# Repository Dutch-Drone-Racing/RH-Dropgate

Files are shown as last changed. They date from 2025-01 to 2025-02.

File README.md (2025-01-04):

# RH-Plugin-Dropgate

A RotorHazard plugin that adds functionality for an automatic dropgate.

## Features

- Control a dropgate using a Raspberry Pi GPIO pin.
- Configure the GPIO pin directly from the RotorHazard settings menu.
- Optionally set up a mirrored timer for advanced synchronization.

---

## Installation

1. **Set up RotorHazard**  
   Install RotorHazard on your Raspberry Pi (Zero or compatible).

2. **Add the Plugin**  
   Copy the entire contents of the `RH-Dropgate-Plugin` directory into the RotorHazard plugin directory on your Raspberry Pi.

3. **Configure GPIO**  
   If you're not using the default GPIO pin (12), specify a different GPIO pin in the RotorHazard settings menu.

4. **Optional: Use a Mirror Timer**  
   For advanced setups, configure a mirror timer as described in the [RotorHazard mirror documentation](https://github.com/RotorHazard/RotorHazard/blob/main/doc/Cluster.md).

---

## Required Hardware

### **Recommended Raspberry Pi**

- **Raspberry Pi Zero W / Zero 2 W**  
   Affordable and compact, ideal for this project.  
- **Other Options (RPI3/4/5)**  
   These are compatible but may require a different case and are more expensive.

---

### **Power Supplies**

- **12V BEC**  
   Ensure at least 5A capacity for the electromagnets.  
   - Recommended: XL4015 or XL4005.

- **5V BEC**  
   Powers the Raspberry Pi.  
   - Example: Mateksys 30 to 5V BEC.

---

### **Relay**

- **12V Relay**  
   Requires a minimum of 5A capacity (higher is better).  
   - Example: [TinyTronics 12V Relay](https://www.tinytronics.nl/nl/schakelaars/relais/12v-relais-1-channel-hoog-actief-of-laag-actief-30a).

---

### **Electromagnets**

- **12V 40mm Electromagnets**  
   Requires 2 magnets. Designed for 40mm versions, such as the 25KG JF-XP4020 model.  
   The dropgate's round bar may reduce the magnet's efficiency, so choose stronger magnets when possible.  
   - Example: [JF-XP4020](https://www.tinytronics.nl/nl/mechanica-en-actuatoren/elektromagneten/elektromagneet-25kg-12v-dc-jf-xp4020).

---

### **Connectors**

- **XT60E Connectors**  
   - 2x XT60EF (Female).  
   - 3x XT60E (Male).

---

### **Optional: Micro USB (OTG) Ethernet Adapter**

While the Raspberry Pi Zero W has WiFi, a wired connection is more stable.

---

### **Double-Sided Tape**

Use tape to secure the relay, 5V BEC, and 12V BEC to the case.  
Recommended: Thick, heat-resistant tape (e.g., "gecko tape").

---

### **M3 Screws**

- **4x M3x6mm**: For the lid.  
- **4x M3x16mm**: For the Raspberry Pi Zero W bracket.  
- **6x M3x12mm**: For the XT60 connectors.

---

### **3D Prints**

- **1x Case**  
- **2x Magnet/Pole Holders**

3D print files are located in the `/prints` folder.

---

### **Other Hardware**

- **32mm Tubes**: Cut to desired lengths/heights.  
- **Aluminum Rod**: Matches the length of your dropgate banner.  
- **Metal Rod Ends**: Attach to the aluminum rod to stick to the magnets.

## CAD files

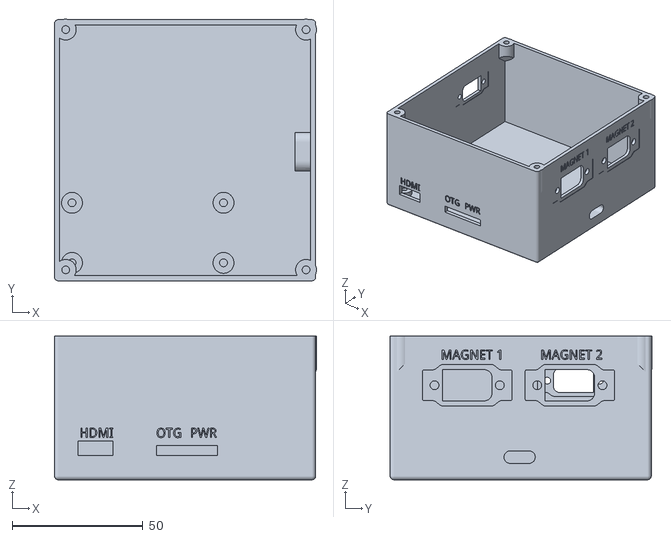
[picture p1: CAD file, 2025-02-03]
prints/Case/dropgate_case_v1_mr30.stl
100.3 x 100.2 x 55.0

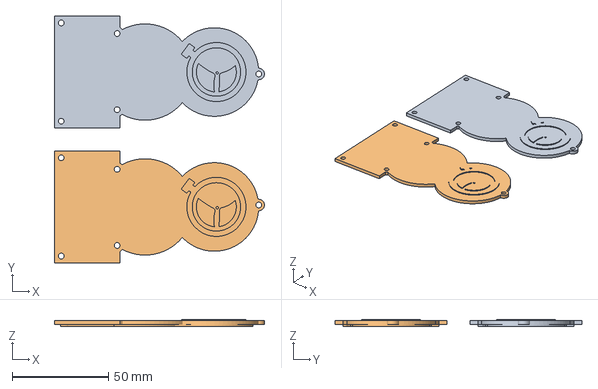
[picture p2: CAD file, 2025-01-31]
prints/Pole/dropgate_polemount_lid_right_logo.3mf
109.0 x 128.0 x 3.50 mm
dropgate_polemount_lid_right_logo.stl
dropgate_polemount_lid_left_logo.stl

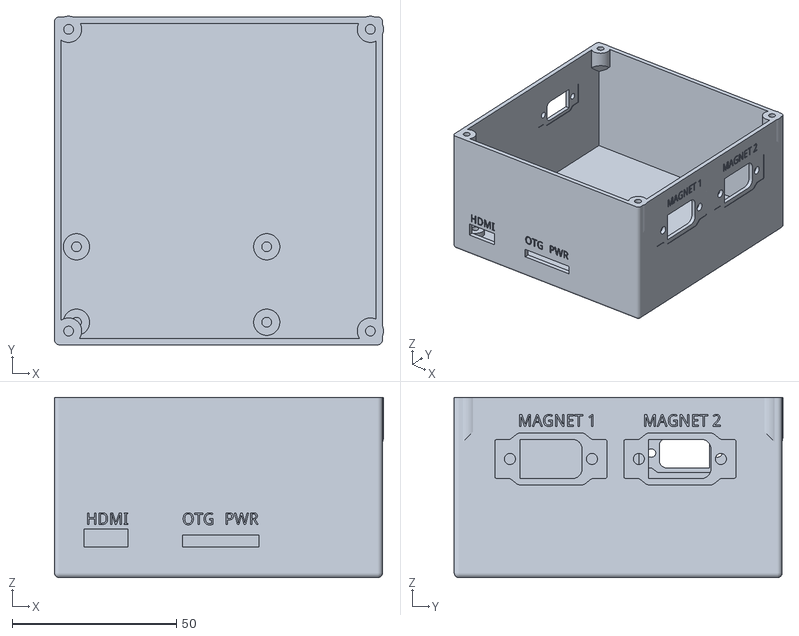
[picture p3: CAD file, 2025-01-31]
prints/Case/dropgate_case_v1.stl
100.3 x 100.2 x 55.0

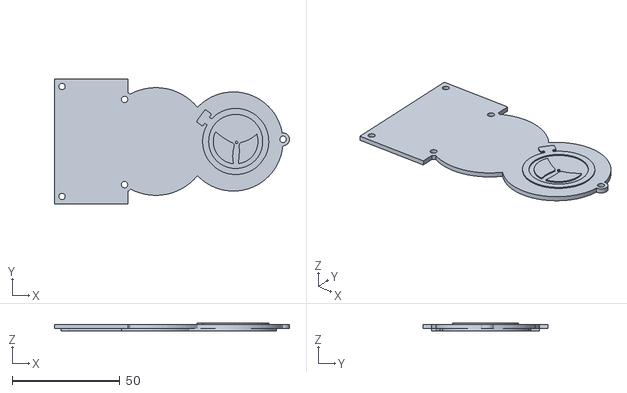
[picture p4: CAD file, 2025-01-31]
prints/Pole/dropgate_polemount_lid_left_logo.stl
109.0 x 58.0 x 3.50

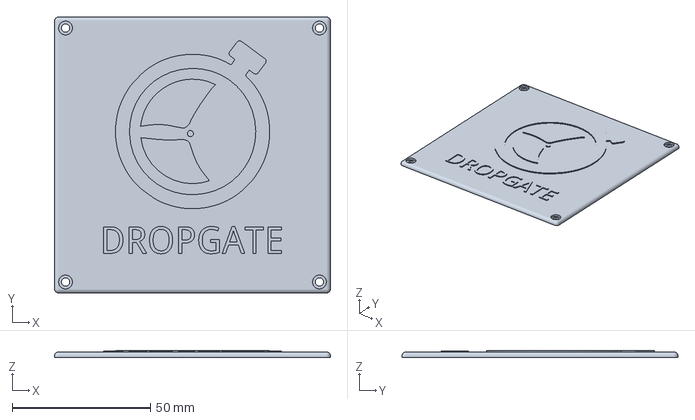
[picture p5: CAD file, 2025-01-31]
prints/Case/dropgate_lid_v1.3mf
100.0 x 100.0 x 2.50 mm

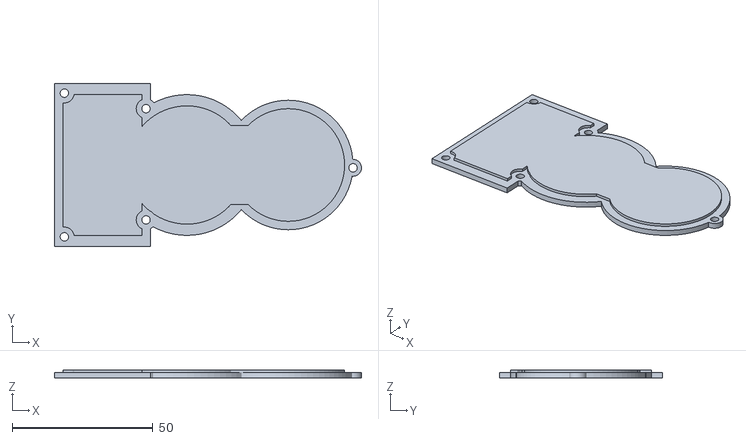
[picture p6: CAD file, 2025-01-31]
prints/Pole/dropgate_polemount_lid_left_nologo.stl
109.0 x 58.0 x 3.00

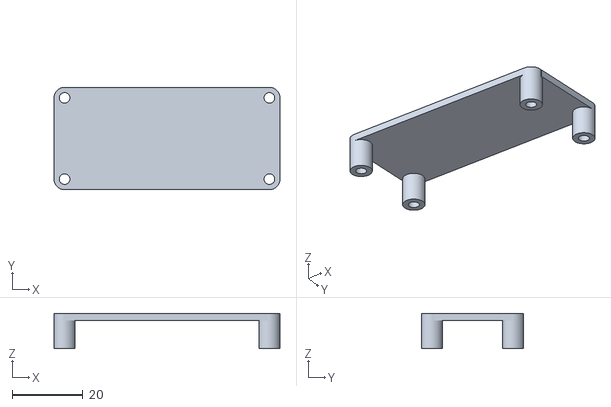
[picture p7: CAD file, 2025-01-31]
prints/Case/dropgate_regulator_bracket_v1.stl
64.0 x 29.0 x 10.0

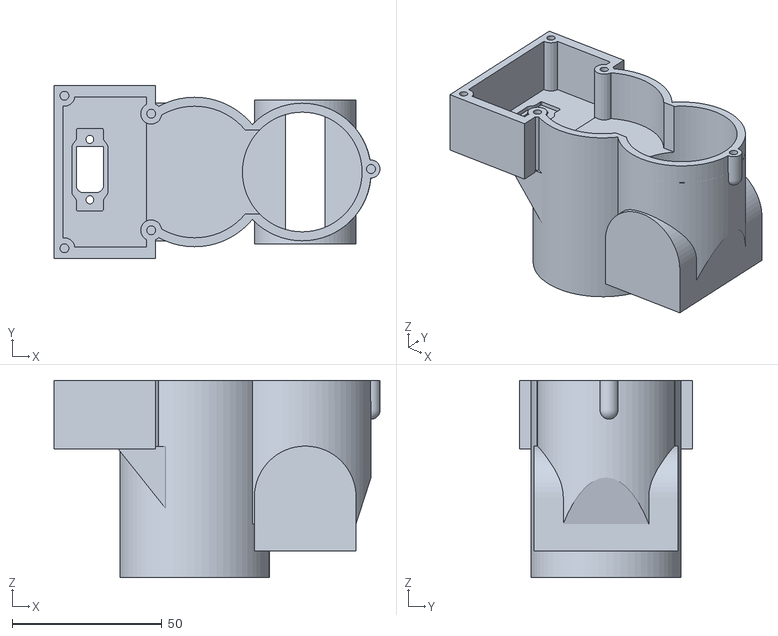
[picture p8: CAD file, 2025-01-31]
prints/Pole/dropgate_polemount_left.stl
109.0 x 58.0 x 66.0

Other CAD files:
prints/Pole/dropgate_polemount_lid_right_nologo.stl
prints/Pole/dropgate_polemount_right.stl
prints/Case/dropgate_lid_v1.stl
prints/Pole/dropgate_polemount_lid_right_logo.stl

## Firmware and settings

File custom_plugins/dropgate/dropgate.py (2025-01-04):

import logging
import RPi.GPIO as GPIO
from RHUI import UIField, UIFieldType, UIFieldSelectOption

class Dropgate():

    def __init__(self,rhapi):
        self.logger = logging.getLogger(__name__)
        self._rhapi = rhapi
        GPIO.setmode(GPIO.BCM)
        GPIO.setwarnings(False)

    def init_plugin(self,args):
        ui = self._rhapi.ui
        ui.register_panel("fpvscores_dropgate", "FPVScores Dropgate", "settings")
        ui_dropgate_gpio = UIField(name = 'fpvscores_dropgate_gpio', label = 'Dropgate GPIO', field_type = UIFieldType.BASIC_INT, desc = "Set the GPIO pin number for the dropgate", value = "12")
        fields = self._rhapi.fields
        fields.register_option(ui_dropgate_gpio, "fpvscores_dropgate")
        self.logger.info("Dropgate is ready")

    def setup_gpio(self, gpio_pin):
        GPIO.setup(gpio_pin, GPIO.OUT)
        GPIO.output(gpio_pin, GPIO.HIGH)

    def trigger_drop(self,args):
        fpvscores_dropgate_gpio = self._rhapi.db.option("fpvscores_dropgate_gpio")
        self.logger.info("Dropping gate on GPIO: %s" % fpvscores_dropgate_gpio)
        self.setup_gpio(fpvscores_dropgate_gpio)
        GPIO.output(fpvscores_dropgate_gpio, GPIO.LOW)

    def reactivate_drop(self,args):
        fpvscores_dropgate_gpio = self._rhapi.db.option("fpvscores_dropgate_gpio")
        self.logger.info("Reactivating gate on GPIO: %s" % fpvscores_dropgate_gpio)
        self.setup_gpio(fpvscores_dropgate_gpio)
        GPIO.output(fpvscores_dropgate_gpio, GPIO.HIGH)

    def gpio_cleanup(self):
        GPIO.cleanup()

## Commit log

2025-01-31 Add 3D prints
    [dropgate_case_v1.stl, dropgate_lid_v1.3mf, dropgate_lid_v1.stl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]
2025-02-03 Adds Case with MR30 connector hole for connecting LED strip/display
    [dropgate_case_v1_mr30.stl]
